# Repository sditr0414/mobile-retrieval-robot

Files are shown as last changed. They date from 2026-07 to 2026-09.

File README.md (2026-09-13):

# Mobile Retrieval Robot

STM32F411 기반 5자유도 로봇팔과 4WD 이동 플랫폼입니다. Flutter 앱으로
HC-05를 통해 차량, 로봇팔, 티칭과 상대 Yaw PID를 제어합니다.

[GitHub 저장소](https://github.com/sditr0414/mobile-retrieval-robot)

[Canva 발표 자료](https://canva.link/0yyf17uj8df1qjl)

[Notion 프로젝트 문서](https://app.notion.com/p/56bdbc6c27e2832ca4c20163aa6199b3)

## 구성

```text
Smartphone ── Bluetooth ── HC-05 ── UART ── STM32F411
                                               ├─ I2C1 ── PCA9685 ── Servo × 6
                                               ├─ I2C3 ── MPU6050
                                               └─ PWM/GPIO ── L298N ── DC Motor × 4
```

## 최종 구성

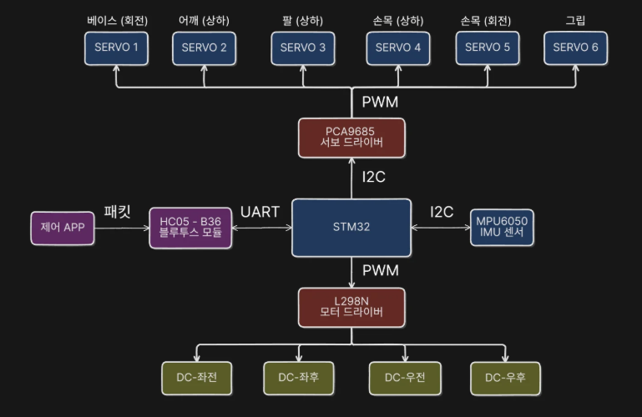
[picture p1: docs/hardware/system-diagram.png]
전체 시스템 다이어그램


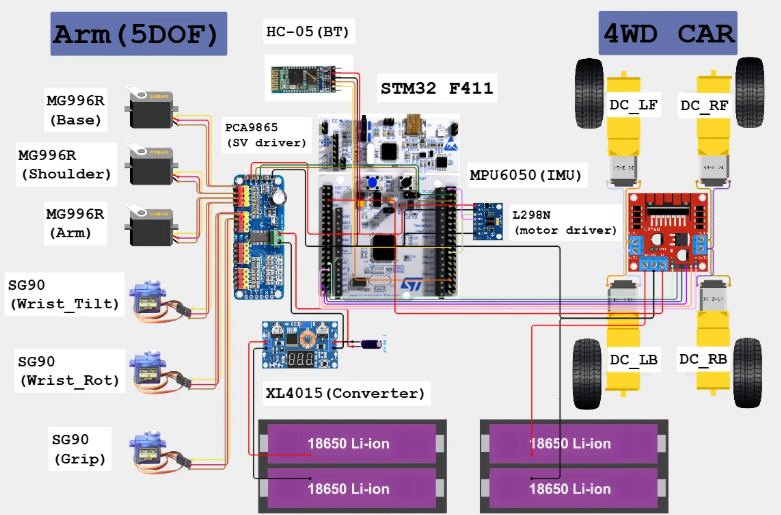
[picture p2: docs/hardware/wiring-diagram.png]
최종 하드웨어 배선도


| 폴더 | 내용 |
|---|---|
| `app/` | Flutter Android 제어 앱 |
| `firmware/` | STM32CubeMX CMake 펌웨어 |
| `simulator/` | PyBullet 로봇팔 시뮬레이터 |
| `docs/` | 하드웨어, 프로토콜, 협업 문서 |

## 구현 상태

- 고정 16바이트 Bluetooth 명령·ACK
- PCA9685 6채널 서보와 S-curve 이동
- L298N 4WD 제어, E-STOP, 500 ms 통신 타임아웃
- 앱 최대 220 PWM과 조절 가능한 PID 직진 판정 범위
- 이름을 포함한 12개 티칭 시퀀스와 PID·서보 보정값의 Sector 7 저장
- MPU6050 상대 Yaw와 직진·후진 방향 안정화 PID
- Flutter 차량·로봇팔·티칭 UI
- PyBullet 관절·패킷·PID 검증

발전 방향: 장애물 감지, 휠 엔코더 기반 정밀 주행, 절대 방향 보정,
역기구학과 XYZ 제어.

## 시작

```powershell
git clone https://github.com/sditr0414/mobile-retrieval-robot.git
cd mobile-retrieval-robot
git switch develop
```

- 앱: [app/README.md](app/README.md)
- 펌웨어: [firmware/README.md](firmware/README.md)
- 시뮬레이터: [simulator/README.md](simulator/README.md)
- 부품과 전원: [docs/hardware/bom.md](docs/hardware/bom.md)
- 핀맵: [docs/hardware/pin-map.md](docs/hardware/pin-map.md)
- PCA9685·S-curve: [docs/hardware/servo-control.md](docs/hardware/servo-control.md)
- 서보 보정: [docs/hardware/servo-calibration.md](docs/hardware/servo-calibration.md)
- IMU: [docs/hardware/imu.md](docs/hardware/imu.md)
- 상대 Yaw PID: [docs/hardware/yaw-pid.md](docs/hardware/yaw-pid.md)
- Bluetooth 규격: [docs/protocol/bluetooth-protocol.md](docs/protocol/bluetooth-protocol.md)
- 협업: [docs/collaboration/CONTRIBUTING.md](docs/collaboration/CONTRIBUTING.md)

## 안전

- 서보와 모터 전원은 STM32에서 공급하지 않습니다.
- 서보용·차량용 2S 팩의 양극은 분리하고 GND만 공통으로 연결합니다.
- 고전류 귀환은 STM32 보드를 경유하지 않습니다.
- 현재 BMS, 퓨즈와 물리 비상정지는 없습니다. 앱 E-STOP은 전원을 물리적으로
  차단하지 않습니다.
- 전원을 넣기 전에 배선, 관절 간섭과 작업 공간을 확인합니다.

<!-- contributor update -->

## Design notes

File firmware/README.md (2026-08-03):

# STM32F411 펌웨어

NUCLEO-F411RE용 STM32CubeMX CMake 프로젝트입니다. HAL과 FreeRTOS
CMSIS-RTOS2를 사용합니다.

## 구현

| 모듈 | 역할 |
|---|---|
| `bluetooth` | USART1 circular DMA와 16바이트 프레임 검증 |
| `servo_driver` | PCA9685 50 Hz PWM |
| `robot_arm` | 6채널 S-curve 이동과 시퀀스 재생 |
| `drive_4wd` | L298N, 타임아웃과 상대 Yaw PID |
| `teaching_storage` | 티칭·설정 Sector 7 저장 |
| `imu` | MPU6050 보정·필터·상대 Yaw |

```text
mobile_retrieval_robot/
├─ App/Inc, App/Src   애플리케이션 모듈
├─ Core/              CubeMX 사용자 코드
├─ Drivers/           STM32 HAL
├─ Middlewares/       FreeRTOS
├─ cmake/             CubeMX CMake
├─ CMakeLists.txt
├─ CMakePresets.json
└─ mobile_retrieval_robot.ioc
```

## CubeMX 기준

| 항목 | 설정 |
|---|---|
| HSE / SYSCLK | 8 MHz bypass / 100 MHz |
| USART1 | PA9/PA10, 9600 8-N-1 |
| RX DMA | DMA2 Stream2, Circular, 128바이트 버퍼 |
| I2C1 | PCA9685, PB8/PB9, 100 kHz |
| I2C3 | MPU6050, PA8/PC9, 100 kHz |
| TIM2 | PSC=4, ARR=999, PA0/PA1, 20 kHz |
| 모터 초기 출력 | GPIO/PWM 모두 0 |

PCA9685가 서보 PWM 50 Hz를 생성합니다. PA2/PA3와 MPU6050 INT는 사용하지
않습니다.

## 실행 구조

| 태스크 | 우선순위 | 역할 |
|---|---|---|
| Bluetooth | AboveNormal | DMA 파싱과 큐 전달 |
| Arm | Normal | 로봇팔, 티칭, 설정, Flash |
| Drive | High | 모터, 타임아웃, PID |
| IMU | BelowNormal | 3초 보정과 20 ms 측정 |
| Status | Low | PID·IMU 상태 송신 |

PCA9685는 `i2cMutex`, MPU6050은 `imuI2cMutex`, Flash는 `flashMutex`로
직렬화합니다. ISR은 파싱, 제어와 Flash 작업을 하지 않습니다.

## 제어와 안전

- 부팅 시 E-STOP 잠금, 차량 정지, 서보 출력 OFF.
- 차량 명령 500 ms 타임아웃.
- 로봇팔·티칭·Flash·IMU 보정 중 차량 인터록.
- 모터 역전 전 중립 정지.
- PCA9685 오류 시 1초마다 재초기화하며 다른 기능은 유지.
- Assert 전 차량 GPIO/PWM을 0으로 설정.

로봇팔은 20 ms 5차 S-curve와 앱 속도 `50~100%`를 사용합니다. `100%`의
각속도 상한은 약 `62.5°/s`입니다. 이동 시간은 20 ms부터 25%씩 늘리며 모든
관절의 속도·가속도·저크 제한을 만족하는 가장 짧은 후보로 결정합니다. 원점은
`[90,90,90,90,90,0]`, 이동 자세는 티칭 시퀀스 9이며 현재 Gripper를
유지합니다. 위치 피드백이 없어 첫 활성화의 실제 시작 위치와 물리 속도는
보장하지 않습니다.

서보 보정값은 Sector 7을 우선합니다. Flash가 비었을 때 일반 관절은
`700/1500/2300 µs`, Gripper는 `1200/1500/1800 µs` 안전 초기값을 사용하며
실측 끝점을 뜻하지 않습니다.

티칭 화면의 편집본은 업로드 임시 버퍼에서 재생하므로 Sector 7을 지우거나
기록하지 않습니다. 저장된 시퀀스 조회와 차량 전용 동작은 부팅 시 Flash에서
읽은 RAM 원본을 사용합니다.

MPU6050은 AD0=GND(`0x68`), 20 ms polling, 2 Hz 필터와 Z축 0.15 dps
deadband를 사용합니다. PID는 직진·후진 구간의 상대 Yaw에만 적용합니다.

## Flash

- Sector 7: `0x08060000`, 128 KiB.
- 링커 FLASH: 384 KiB.
- 현재 버전 저장 이미지는 2,516바이트이며 기록 전 Sector 7 전체를 삭제.
- 형식 버전 8, CRC와 기록 후 재검증.
- 이름을 포함한 12개 시퀀스, PID, 서보 3점 보정, 호환용 이동 자세 5바이트.
- 버전 2~7은 웨이포인트와 설정을 보존하고 기본 이름을 추가하며, 버전 1은
  Gripper 의미가 달라 거부.
- 설정 조각은 RAM에 모두 받은 뒤 COMMIT에서 한 번 기록.
- Sector 삭제·기록 중 전원을 끄면 저장 이미지가 무효화될 수 있으므로 완료 ACK 후
  전원을 차단.

정확한 패킷과 저장 ACK는
[Bluetooth 프로토콜](../docs/protocol/bluetooth-protocol.md)을 따릅니다.

## 빌드

```powershell
cd firmware/mobile_retrieval_robot
cmake --preset Debug
cmake --build --preset Debug
```

## 남은 실기 튜닝

- Wrist Tilt 포함 관절 안전 끝점
- 실제 차체 PID 계수

전원, MPU6050 장착 방향과 L298N 전진 극성은 실물에 적용되어 있습니다.
구체적인 전원 모델·출력값은 저장소 문서에 기록하지 않았습니다.

관련 문서: [핀맵](../docs/hardware/pin-map.md),
[서보 보정](../docs/hardware/servo-calibration.md),
[PCA9685·S-curve](../docs/hardware/servo-control.md),
[IMU](../docs/hardware/imu.md),
[상대 Yaw PID](../docs/hardware/yaw-pid.md).

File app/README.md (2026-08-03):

# Flutter 제어 앱

HC-05 Bluetooth Classic SPP로 STM32를 제어하는 Android 앱입니다.

## 실행

스마트폰에서 HC-05를 먼저 페어링합니다.

```powershell
cd app
flutter pub get
flutter run
```

Android Bluetooth 권한, 외부 구동 전원, 공통 GND와 로봇 작업 공간을 먼저
확인합니다.

## 화면

| 화면 | 기능 |
|---|---|
| 차량 | 조이스틱, 전용 시퀀스, PID 설정·상태 |
| 로봇팔 | 6채널 수동 제어, 속도, 원점 보정 |
| 티칭 | 웨이포인트 편집, Flash 업로드·재생·초기화 |

연결과 STOP은 모든 화면에서 접근할 수 있습니다. 세로 화면은 아래쪽, 가로
화면은 왼쪽 탐색 메뉴를 사용합니다.

## 최초 연결

1. HC-05에 연결합니다.
2. 초기 STOP 잠금을 사용자 확인 후 해제합니다.
3. 로봇팔 화면에서 `원점으로 이동`을 눌러 출력을 활성화합니다.
4. 실제 원점 도착을 눈으로 확인합니다.
5. 차량 화면 진입 시 티칭 시퀀스 9가 완료될 때까지 기다립니다.

일반 서보에는 위치 피드백이 없습니다. 앱의 값은 실측 위치가 아니라 마지막
명령입니다. 로봇팔 ACK가 10초 동안 없으면 앱은 STOP을 요청합니다.

## 차량

- 조이스틱 입력 중 약 100 ms마다 명령 전송.
- 조이스틱 최대 출력은 `220 PWM`이며 펌웨어 PID가 사용할 보정 여유를 남김.
- 손을 떼면 정지. 펌웨어는 500 ms 타임아웃 적용.
- 차량 화면 진입 시 이동 자세인 시퀀스 9 재생.
- 이동 자세 실행 중 그리퍼는 현재값 유지.

| 시퀀스 | 용도 | 조건 |
|---:|---|---|
| 9 | 이동 자세 | 차량 화면 진입·이동 요청 |
| 10 | 잡기 위치 | 독립 실행 |
| 11 | 잡기 | 시퀀스 10 완료 후 |
| 12 | 놓기 | 시퀀스 11 완료 후 |

시퀀스 9~12는 이름을 바꿀 수 없으며 잠금 아이콘과 용도별 색으로 구분합니다.
시퀀스 11 뒤 첫 주행과 시퀀스 12 완료 뒤에는 그리퍼를 유지한 이동 자세를
먼저 실행합니다. 실제 자세는 티칭 후 Flash에 업로드합니다.

PID는 차량 화면 팝업에서 저장·활성화합니다.

- Kp `0.00~2.55`, Ki/Kd `0~100`.
- 초기값 `2.00/1.40/0.00`.
- 조이스틱 직진 판정 범위는 `0.00~1.00`, 기본 `0.10`.
- PID 직진 중에는 판정 범위를 `+0.04` 넓혀 경계에서 반복 전환되는 것을 방지.
- 직진 판정 범위는 앱 실행 중 유지되며 STM32 Flash에는 저장하지 않음.
- MPU6050 보정 완료와 STOP 해제 후 활성화 가능.
- 회전에는 적용하지 않고 직진·후진 구간의 상대 Yaw만 유지.
- ACK의 실제 적용 상태만 `PID 적용 중`으로 표시.
- 목표·현재 Yaw, 오차, 출력, 좌우 PWM과 온도를 표시.
- 상태가 1.5초 이상 갱신되지 않으면 수신 대기로 표시.

## 로봇팔

| 대상 | 표시 범위 |
|---|---:|
| Base~Wrist Rotate | `-90~+90°` |
| Gripper | 열림 `0%`~닫힘 `100%` |
| 속도 | `50~100%` |

원점은 5관절 `0°`, Gripper `0%`입니다. 이동은 20 ms 5차 S-curve를 사용합니다.
속도 `100%`의 각속도 상한은 약 `62.5°/s`이며 이동 시간은 6개 관절의
속도·가속도·저크 제한을 모두 만족하도록 자동 결정됩니다.
슬라이더 트랙 탭은 값이 순간 이동하지 않으며 `-`/`+`는 짧게 누르면 한 단계,
300 ms 이상 누르면 연속 조정합니다.

### 원점 보정

1. `원점 보정`을 누르고 전체 원점 이동 ACK를 기다립니다.
2. Base부터 Gripper까지 한 관절씩 선택합니다.
3. 일반 관절은 `-90/0/+90°`, Gripper는 열림/닫힘 펄스를 조정합니다.
4. `확인 시퀀스`로 시험합니다.
5. `원점 보정 저장`으로만 Sector 7에 기록합니다.

| 대상 | 펄스 범위 |
|---|---:|
| Base~Wrist Rotate | `350~2650 µs` |
| Gripper | `1000~2000 µs` |

보정 중 다른 관절은 원점을 유지하고 차량은 잠깁니다. 자세와 실측값은
[서보 보정 문서](../docs/hardware/servo-calibration.md)를 기준으로 합니다.

## 티칭

- 12개 시퀀스, 시퀀스당 최대 30개 웨이포인트.
- 시퀀스 1~8은 UTF-8 21바이트 이하 이름을 지정해 웨이포인트와 함께 저장.
- 시퀀스 9~12는 이동 자세·잡기 위치·잡기·놓기 고정 이름 사용.
- 로봇팔 화면에서 현재 자세를 앱 목록에 추가·삭제.
- 티칭 화면에서 각도 수정, 편집본 재생과 Flash 저장·초기화.
- HC-05 연결 후 티칭 화면에 들어가면 저장된 시퀀스 이름을 불러옴.
- 업로드·초기화 중 화면 전환과 데이터 수정 잠금.
- 미저장 편집본은 시퀀스 변경 또는 앱 종료 시 폐기.
- 성공 ACK를 받은 뒤에만 저장·초기화 완료로 표시.
- 저장·초기화 완료 안내 전에는 앱을 종료하거나 로봇 전원을 끄지 않음.
- `시퀀스 재생`은 현재 편집본을 임시 전송하므로 Flash 저장 없이 바로 반영.
- 재생 완료 ACK 뒤 마지막 웨이포인트를 로봇팔 수동 제어 화면에 반영.
- 이동 자세는 마지막 웨이포인트의 5관절만 반영하고 현재 Gripper 값을 유지.
- 저장하지 않고 다른 시퀀스를 고르면 변경을 버리고 선택한 Flash 원본을 자동 조회.
- 차량 화면의 이동·잡기 위치·잡기·놓기는 편집본이 아닌 Flash 저장본 재생.
- 저장본의 마지막 자세 조회부터 재생 완료까지 중복 조작을 잠그며, 조회 실패 시
  실제 동작을 시작하지 않음.

## TEST 모드

화면 제목을 길게 눌러 Bluetooth 없는 기능 확인 모드를 켭니다. 실제 패킷이나
Flash를 변경하지 않으며 실제 Bluetooth 연결 중에는 시작할 수 없습니다.

## 프로토콜과 점검

패킷은 고정 16바이트입니다. 바이트 규격은
[Bluetooth 프로토콜](../docs/protocol/bluetooth-protocol.md)을 따릅니다.

```powershell
cd app
flutter analyze
flutter test
flutter build apk --debug
```

`flutter_classic_bluetooth 0.1.8`은 현재 빌드되지만 Kotlin Gradle 적용 경고가
있습니다. Flutter가 해당 방식을 제거하기 전에 대체 플러그인을 실기기에서
검증합니다.

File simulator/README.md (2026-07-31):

# PyBullet 시뮬레이터

앱·펌웨어와 같은 관절 순서, 방향과 Mode 1 패킷을 PC에서 확인하는 독립 검증
도구입니다.

## 설치와 실행

```powershell
cd simulator
python -m venv .venv
.\.venv\Scripts\Activate.ps1
python -m pip install -r requirements.txt
python main.py
```

```powershell
python main.py --pose travel
python main.py --emit-packets --speed 50
python main.py --direct --duration 0.2 --no-realtime-sleep
```

Windows는 `pybullet-arm64`, 다른 운영체제는 `pybullet`을 사용하도록
`requirements.txt`에 조건이 설정되어 있습니다.

## 기준

| 대상 | 값 |
|---|---|
| 관절 | Base, Shoulder, Elbow, Wrist Tilt, Wrist Rotate, Gripper |
| 앱 범위 | 5관절 `-90~+90°`, Gripper `0~100%` |
| URDF 부호 | `[-1,-1,+1,-1,-1]` |
| 원점 | `[0,0,0,0,0]`, Gripper `0%` |
| 이동 자세 | `[0,-50,90,0,60]`, Gripper `0%`로 시작 |

실제 펌웨어의 이동 자세는 티칭 시퀀스 9이며 현재 Gripper를 유지합니다.
시뮬레이터의 범위와 이동 자세는 실물 안전 범위가 아닙니다.

`protocol.py`는 다음 고정 16바이트 Mode 1 프레임을 생성합니다.

```text
[AA,01,Base,Shoulder,Elbow,WristTilt,WristRotate,Gripper,
 Control,TransactionId,Speed,00,00,00,Checksum,55]
```

## 검증

```powershell
python -m unittest discover -s tests -v
python tools\validate_model.py
python main.py --direct --duration 0.1 --pose travel --emit-packets --no-realtime-sleep
```

모델 검사는 URDF, 메시, 질량, 관성텐서, 관절 설정과 DIRECT 로딩을 확인합니다.

## 활용과 확장

- 질량은 실측값, 링크 길이는 캡처 치수를 5 mm 단위로 정리한 값입니다.
- 무게중심·관성·충돌 형상은 관절과 패킷 검증용 근사값입니다.
- 기본 중력은 0이며 `drive_pid.py`로 펌웨어 PID 계산을 재현합니다.
- 실측 동역학, 차량 모델과 역기구학을 추가해 검증 범위를 넓힐 수 있습니다.

모델 세부값은 [models/README.md](models/README.md)를 확인합니다.

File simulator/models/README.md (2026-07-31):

# 로봇팔 모델

`robot_arm.urdf`와 영문 `snake_case` STL을 보관합니다. 질량은 실측값이며
무게중심·관성텐서와 충돌 형상은 PyBullet용 근사값입니다.

## 질량

| 구분 | 합계 |
|---|---:|
| 출력 부품 16개 | 269.22 g |
| MG996R 3개 | 165.00 g |
| SG90 3개 | 27.00 g |
| URDF 전체 | 461.22 g |

볼트, 너트, 혼과 배선은 포함하지 않습니다. 부품별 값은
`mass_properties.json`, 검증 상태는 `model_parameters.json`이 기준입니다.

## 링크 길이

| 구간 | URDF |
|---|---:|
| 베이스 높이 | 60 mm |
| Base–Shoulder | 40 mm |
| Shoulder–Elbow | 120 mm |
| Elbow–Wrist | 120 mm |
| Wrist–Gripper 끝 | 125 mm |

## STL 방향

- Base: 수직축 180°
- Base cover: 높이 0 mm
- Central shaft: 높이 60 mm, X축 -90°
- Upper arm: 링크축 왼쪽 90°, 앞뒤 180°
- Wrist: Y축 180°
- Gripper: 링크축 왼쪽 90°

Base와 Base cover는 고정부품입니다. Gripper는 반대 방향으로 회전하는 두
링크로 근사합니다. 관절 제한, 토크와 충돌 안전 판단에는 사용하지 않습니다.

기준 이미지는 `left_side_view.png`, `right_side_view.png`, `top_view.png`,
`bottom_view.png`, `back_view.png`, `gripper_front_view.png`입니다.

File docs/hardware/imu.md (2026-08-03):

# MPU6050

상대 Yaw PID의 수식, 적용 조건과 튜닝은
[상대 Yaw PID 제어 문서](yaw-pid.md)를 참고합니다.

## 연결

| MPU6050 | NUCLEO-F411RE |
|---|---|
| VCC | 실물 적용, 공급전압 문서 미기록 |
| GND | 공통 GND |
| SCL / SDA | PA8 / PC9 |
| AD0 | GND, 주소 `0x68` |
| INT | 미사용 |

MPU6050은 I2C3 100 kHz와 전용 `imuI2cMutex`를 사용합니다. PCA9685의
I2C1과 분리되어 센서 버스 오류가 서보 통신에 영향을 주지 않습니다.

## 동작

1. 호환 센서 ID `0x68`, `0x70`, `0x71`, `0x73` 확인.
2. 가속도 ±2g, 자이로 ±250 dps 설정.
3. 정지 상태에서 3초 자이로 영점 보정.
4. 20 ms마다 측정하고 2 Hz 저역통과 필터 적용.
5. X/Y축 0.30 dps, Z축 0.15 dps deadband 적용.
6. Z축 각속도를 적분해 `-180~+180°` 상대 Yaw 생성.

PID를 켤 때도 차량을 먼저 정지하고 3초 영점 보정을 다시 수행합니다. 앱은 보정
완료 ACK를 받은 뒤 PID 활성화를 요청합니다.

센서 오류 시 1초마다 재연결합니다. 수동 차량·로봇팔·티칭은 유지하지만 PID를
끄고 차량을 정지한 뒤 새 주행 명령을 요구합니다.

## 방향 PID

- 직진·후진 시작 시 현재 Yaw를 목표로 저장.
- 회전에는 PID를 적용하지 않음.
- 장착 방향 보정 부호 `-1`, 후진 시 다시 반전.
- 적분항 `±50`, 최종 보정 `±80 PWM` 제한.
- 앱의 기본 주행 PWM은 최대 `220`; 펌웨어 PID 출력은 `0~255` 범위에서 보정.
- 정지, 회전, 방향 전환, E-STOP, 타임아웃과 인터록에서 상태 초기화.
- 초기 계수 `Kp=2.00`, `Ki=1.40`, `Kd=0.00`.

MPU6050에는 자력계가 없어 절대 Yaw를 보정하지 않습니다. 온도는 앱 표시용이며
보정에는 사용하지 않습니다. 장착 방향과 필터·PID 계수는 실제 차체에서 다시
확인합니다.

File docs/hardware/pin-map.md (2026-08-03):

# NUCLEO-F411RE 핀맵

현재 `.ioc`와 펌웨어 기준입니다.

## STM32 핀 배치

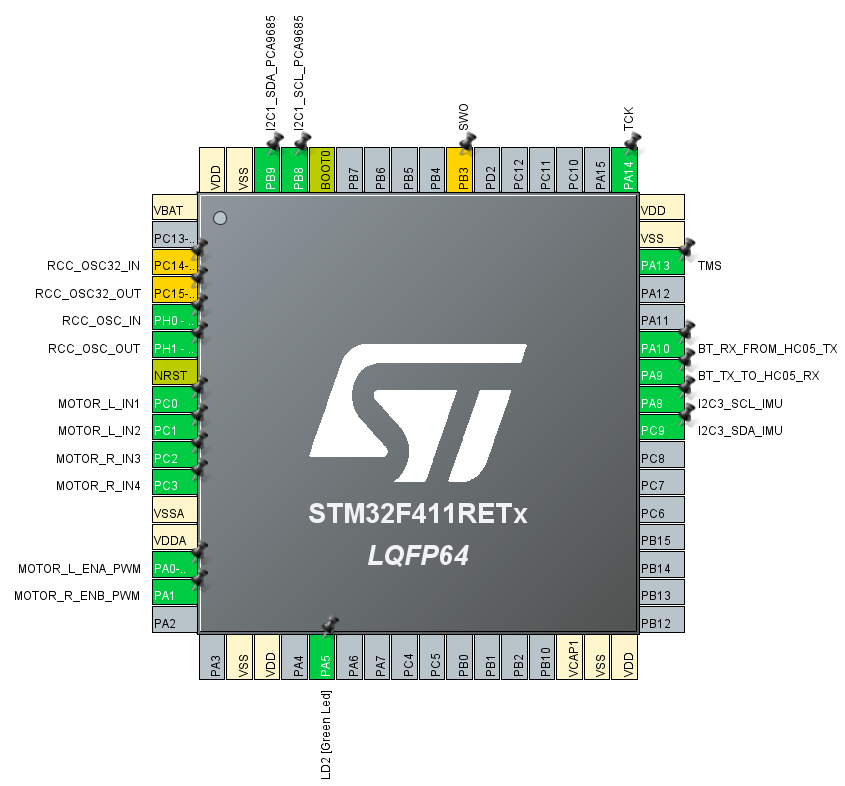
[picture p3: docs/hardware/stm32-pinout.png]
STM32F411RE CubeMX 핀 배치


## 최종 배선도

최종 하드웨어 배선도

## I2C1

| 장치 핀 | STM32 | 조건 |
|---|---|---|
| PCA9685 SCL | PB8 | `I2C1_SCL_PCA9685` |
| PCA9685 SDA | PB9 | `I2C1_SDA_PCA9685` |

PCA9685 주소는 `0x40`, 통신 속도는 100 kHz입니다.

## I2C3

| 장치 핀 | STM32 | 조건 |
|---|---|---|
| MPU6050 SCL | PA8 | `I2C3_SCL_IMU` |
| MPU6050 SDA | PC9 | `I2C3_SDA_IMU` |
| MPU6050 AD0 | GND | 주소 `0x68` |
| MPU6050 INT | 미연결 | 20 ms polling |
| MPU6050 VCC | 실물 적용 | 공급전압 문서 미기록 |

통신 속도는 100 kHz입니다. 두 모듈의 pull-up과 논리 전압은 실물에서 각각
확인합니다.

## Bluetooth

| 기능 | STM32 | HC-05 |
|---|---|---|
| USART1 TX | PA9 | RXD |
| USART1 RX | PA10 | TXD |

설정은 9600 baud, 8-N-1입니다.

## L298N

| 기능 | STM32 | 역할 |
|---|---|---|
| ENA | PA0 / TIM2_CH1 | 왼쪽 20 kHz PWM |
| IN1 | PC0 | 왼쪽 방향 |
| IN2 | PC1 | 왼쪽 방향 |
| ENB | PA1 / TIM2_CH2 | 오른쪽 20 kHz PWM |
| IN3 | PC2 | 오른쪽 방향 |
| IN4 | PC3 | 오른쪽 방향 |

ENA/ENB 점퍼를 제거합니다. 좌우 전진 극성은 실제 L298N·모터 배선에 맞춰 적용했습니다.

## 기타

| 기능 | 핀 |
|---|---|
| SWD | PA13, PA14 |
| 예비 | PA2, PA3 |

## 전원·GND

- PCA9685 `VCC`: STM32 논리 전원.
- PCA9685 `V+`: XL4015 서보 전원.
- PCA9685 `V+`–GND: 1000 µF 전해 커패시터.
- 차량용 2S: L298N 모터 전원.
- STM32, PCA9685, L298N, HC-05, MPU6050과 두 전원은 공통 GND.
- 서보·모터 고전류 귀환은 STM32 보드를 경유하지 않음.
- STM32 VIN용 DC-DC는 실물 적용 완료. 모델·출력값은 문서 미기록.

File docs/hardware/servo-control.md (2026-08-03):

# PCA9685와 S-curve 서보 제어

이 문서는 로봇팔의 목표 자세가 PCA9685 PWM 출력으로 변환되는 과정과
서보를 부드럽게 움직이는 5차 S-curve를 설명합니다. 발표 자료의 제어 흐름을
참고하되, 수치와 채널은 현재 펌웨어를 기준으로 합니다.

전체 시스템 다이어그램

## 전체 흐름

```text
앱의 목표 자세와 속도
  → 16바이트 Bluetooth 패킷
  → 5차 S-curve 궤적 계산
  → 20 ms마다 다음 관절 위치 계산
  → 관절별 3점 보정으로 펄스폭 변환
  → 펄스폭을 PCA9685 12비트 Count로 변환
  → I2C1 레지스터 기록
  → 서보 PWM 출력
```

## PCA9685 역할

STM32의 타이머 채널을 서보마다 사용하지 않고 PCA9685 한 개가 6개 서보의
PWM을 생성합니다. 모든 채널은 같은 50 Hz 주기를 사용하지만 펄스폭은 채널마다
독립적으로 설정합니다.

| 항목 | 현재 설정 |
|---|---|
| 연결 | I2C1 PB8/PB9, 100 kHz |
| 주소 | `0x40` |
| PWM 주파수 | 50 Hz |
| PWM 주기 | 20,000 µs |
| 분해능 | 12비트, 4,096 Count |
| Prescale | 121 |
| 사용 채널 | 0~5 |

| 채널 | 관절 |
|---:|---|
| 0 | Base |
| 1 | Shoulder |
| 2 | Elbow |
| 3 | Wrist Tilt |
| 4 | Wrist Rotate |
| 5 | Gripper |

Canva의 `1056 µs → 216 Count`는 변환 과정을 보여주는 예시입니다. 실제 Shoulder
출력은 현재 채널 1을 사용하며, 펄스폭은 저장된 관절 보정값에 따라 달라집니다.

### I2C 통신 방식

STM32가 Master, PCA9685가 Slave입니다. SCL은 STM32가 만드는 클록이고 SDA는
주소·레지스터·데이터를 주고받는 선입니다. 두 선은 Open-drain 방식이므로 pull-up이
필요합니다. 실제 모듈의 pull-up 저항값은 문서에 기록되지 않아 임의로 지정하지
않습니다.

PCA9685의 7비트 주소는 `0x40`입니다. I2C 버스에서는 이 주소 뒤에 Read/Write
비트가 붙습니다.

```text
7비트 장치 주소 : 0x40 = 100 0000₂
Write 주소 바이트: 0x80 = 1000 0000₂
Read 주소 바이트 : 0x81 = 1000 0001₂
```

STM32 HAL은 주소 인수에 Read/Write 비트가 들어갈 자리를 포함하므로 코드에서는
`0x40 << 1`, 즉 `0x80`을 `HAL_I2C_Mem_Write()`에 전달합니다. HAL이 실제 전송
방향에 맞춰 최하위 비트를 처리합니다.

한 채널을 기록하는 순서는 다음과 같습니다.

```text
START
  → PCA9685 주소 + Write
  → ACK
  → 시작 레지스터 주소
  → ACK
  → ON_L → ACK → ON_H → ACK → OFF_L → ACK → OFF_H → ACK
  → STOP
```

`MODE1`의 Auto Increment를 켰기 때문에 시작 레지스터 하나를 지정한 뒤 네 바이트를
연속 전송할 수 있습니다. 펌웨어의 `HAL_I2C_Mem_Write()`가 START, 주소, ACK 확인,
레지스터 주소와 데이터 전송, STOP을 처리합니다. ACK가 없거나 100 ms 안에 전송이
끝나지 않으면 오류를 반환합니다.

### 채널 레지스터

채널마다 ON 시점과 OFF 시점을 저장하는 네 레지스터가 있습니다.

| 순서 | 레지스터 | 내용 |
|---:|---|---|
| 0 | `LEDn_ON_L` | ON Count 하위 8비트 |
| 1 | `LEDn_ON_H` | ON Count 상위 4비트, Full ON 비트 |
| 2 | `LEDn_OFF_L` | OFF Count 하위 8비트 |
| 3 | `LEDn_OFF_H` | OFF Count 상위 4비트, Full OFF 비트 |

채널 0의 시작 주소는 `0x06`이고, 다음 채널은 네 바이트 뒤에 있습니다.

```text
채널 n 시작 주소 = 0x06 + 4 × n

채널 0 Base          : 0x06
채널 1 Shoulder      : 0x0A
채널 2 Elbow         : 0x0E
채널 3 Wrist Tilt    : 0x12
채널 4 Wrist Rotate  : 0x16
채널 5 Gripper       : 0x1A
```

### 12비트 카운터

12비트는 `2¹² = 4096`단계를 표현합니다. 내부 카운터는 한 PWM 주기 동안
`0~4095`를 반복합니다. Count가 ON 값에 도달하면 출력이 활성화되고 OFF 값에
도달하면 비활성화됩니다.

```text
Count: 0 ───────────────────────────────────────────── 4095
       ↑ ON=0                 ↑ OFF=N
       └────── HIGH 구간 ─────┘
```

현재 펌웨어는 모든 채널의 ON Count를 0으로 두고 OFF Count만 바꿉니다. 따라서
OFF Count가 곧 펄스폭을 나타냅니다. ON과 OFF 값을 모두 다르게 주면 펄스의 시작
위치도 옮길 수 있지만, 일반 서보 제어에는 필요하지 않아 사용하지 않습니다.

### 펄스폭을 Count로 변환

20,000 µs를 4,096등분하므로 한 Count는 약 4.883 µs입니다.

```text
OFF Count = round(펄스폭 µs × 4096 / 20000)
```

예를 들어 1,500 µs는 307 Count이고 `0x0133`입니다. Shoulder 채널 1에 이를
출력하면 시작 주소 `0x0A`부터 다음 네 바이트를 기록합니다.

```text
LED1_ON_L  = 0x00
LED1_ON_H  = 0x00
LED1_OFF_L = 0x33
LED1_OFF_H = 0x01
```

Canva의 1,056 µs 예시는 같은 식으로 약 216 Count가 됩니다.

```text
round(1056 × 4096 / 20000) = 216
```

상위 레지스터에는 Count의 상위 4비트만 저장합니다. 비트 4는 일반 Count가 아니라
Full ON 또는 Full OFF 제어 비트입니다. 전체 출력 차단 시에는
`ALL_LED_OFF_H`의 Full OFF 비트를 사용합니다.

### 50 Hz와 Prescale

PCA9685의 모든 채널은 하나의 PWM 주파수를 공유합니다. 내부 발진기의 대표값
25 MHz를 사용할 때 주파수와 Prescale 관계는 다음과 같습니다.

```text
PWM 주파수 = 발진 주파수 / (4096 × (Prescale + 1))
Prescale = round(발진 주파수 / (4096 × 목표 주파수)) - 1

50 Hz 설정 = round(25,000,000 / (4096 × 50)) - 1 ≈ 121
```

대표 발진값으로 계산하면 `Prescale=121`에서 약 50.03 Hz입니다. 실제 내부 발진기는
오차가 있으므로 정확한 펄스폭이 필요하면 출력 주기를 측정하고 서보 3점 보정값에
반영합니다.

### 각도를 펄스폭으로 변환

서보마다 중앙과 양 끝의 실제 펄스폭이 다르므로 하나의 고정 비율을 사용하지
않습니다. `-90°`, `0°`, `+90°`에서 저장한 세 점을 두 구간으로 나눠 선형
보간합니다.

```text
-90° ~ 0°  : 최소 펄스 ↔ 중앙 펄스
  0° ~ 90° : 중앙 펄스 ↔ 최대 펄스
```

앱의 일반 관절 `-90~+90°`는 패킷 내부의 `0~180`으로 전달됩니다. Gripper는
앱의 열림 `0%`부터 닫힘 `100%`를 내부 `0~180`으로 변환합니다. 조립 방향이
반대인 관절은 펄스 변환 전에 논리 위치를 반전합니다.

보정 가능한 범위는 일반 관절 `350~2650 µs`, Gripper `1000~2000 µs`입니다.
실측값은 [서보 보정 문서](servo-calibration.md)를 기준으로 합니다.

### 초기화와 출력 차단

1. I2C 장치 응답 확인.
2. `MODE1`을 읽고 Auto Increment와 Sleep 설정.
3. `PRE_SCALE=121` 기록.
4. Sleep 해제 후 1 ms 대기.
5. Restart와 Totem-pole 출력 설정.
6. 부팅 직후 모든 채널을 Full OFF로 유지.

PCA9685 통신은 전용 `i2cMutex`로 보호합니다. I2C 기록에 실패하면 로봇팔
출력을 차단하고 상위 태스크가 1초 간격으로 재초기화를 시도합니다.

## 5차 S-curve

목표 각도를 즉시 PWM에 적용하면 속도와 가속도가 갑자기 변해 충격, 기구 흔들림,
전류 피크가 커질 수 있습니다. 현재 펌웨어는 위치를 5차 다항식으로 만들고 20 ms
간격으로 조금씩 출력합니다.

```text
p(t) = a0 + a1t + a2t² + a3t³ + a4t⁴ + a5t⁵
```

계수는 다음 경계 조건을 만족하도록 계산합니다.

- 시작: 현재 위치, 현재 속도, 현재 가속도.
- 종료: 목표 위치, 속도 0, 가속도 0.

정지 상태에서 출발하는 기본 형태는 정규화 시간 `u=t/T`에 대해 다음과 같습니다.

```text
s(u) = 10u³ - 15u⁴ + 6u⁵,  0 ≤ u ≤ 1
p(t) = 시작 위치 + (목표 위치 - 시작 위치) × s(u)
```

`T`는 전체 이동 시간입니다. `u`는 현재 경과 시간 `t`를 `T`로 나눈 값입니다.
따라서 시작과 끝에서는 변화량이 작고 중간에서는 커져, 느리게 출발하고 가속한 뒤
목표 근처에서 다시 감속합니다.

### 속도와 이동 시간

앱 속도는 `50~100%`입니다. 최대 각속도는 다음 식을 사용합니다.

```text
최대 각속도 = 1000 / 16 × 속도 비율
             = 62.5 × 속도 비율 (°/s)
```

| 앱 속도 | 최대 각속도 |
|---:|---:|
| 50% | 약 31.25°/s |
| 80% | 약 50.0°/s |
| 100% | 약 62.5°/s |

가속 기준 시간은 `12 × 20 ms = 240 ms`입니다. 펌웨어는 이 값으로 최대
가속도와 저크를 계산합니다.

```text
최대 가속도 = 최대 각속도 / 0.24
최대 저크   = 최대 가속도 / 0.24
```

이동 시간은 고정값이 아닙니다. 20 ms부터 시작해 후보 시간을 25%씩 늘리며,
6개 관절이 모두 위치 범위와 속도·가속도·저크 제한을 지키는 가장 짧은 시간을
선택합니다. 후보 하나는 32개 구간으로 검사하며 모든 관절이 같은 시점에 끝납니다.

### 이동 중 목표 변경

새 목표가 들어오면 현재 위치뿐 아니라 현재 속도와 가속도도 시작 조건으로 사용해
새 5차 궤적을 만듭니다. 연속 궤적이 관절 범위를 벗어나면 현재 위치에서 속도와
가속도를 0으로 만든 뒤 다시 계획합니다. 지연된 20 ms 호출을 한꺼번에 실행하지
않아 I2C 출력이 순간적으로 몰리는 것도 막습니다.

## 제어의 한계

- 일반 서보에는 위치 피드백이 없어 현재 위치는 마지막 명령값입니다.
- S-curve는 명령 변화를 부드럽게 하지만 전원 부족, 전압 강하, 기구 걸림을
  해결하지는 않습니다.
- 끝점은 서보와 조립 상태마다 다르므로 앱에서 실측 보정해야 합니다.
- PCA9685의 실제 발진 오차가 크면 오실로스코프로 주기와 펄스폭을 확인한 뒤
  보정값을 다시 측정합니다.

## 구현 위치

- PCA9685 초기화·출력: `firmware/mobile_retrieval_robot/App/Src/servo_driver.c`
- S-curve·관절 제어: `firmware/mobile_retrieval_robot/App/Src/robot_arm.c`
- 실측 펄스: `docs/hardware/servo-calibration.md`
- 핀과 전원: `docs/hardware/pin-map.md`
- 발표 자료: [Canva 프레젠테이션](https://canva.link/0yyf17uj8df1qjl)
- 칩 규격: [NXP PCA9685 데이터시트](https://www.nxp.com/docs/en/data-sheet/PCA9685.pdf)

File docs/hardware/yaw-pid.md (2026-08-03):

# MPU6050 상대 Yaw PID 제어

이 문서는 MPU6050으로 계산한 상대 Yaw를 이용해 4WD 차량의 직진·후진 방향을
보정하는 과정을 설명합니다. 수식과 제한값은 현재 펌웨어를 기준으로 합니다.

전체 시스템 다이어그램

## 제어 목적

좌우 모터에 같은 PWM을 주어도 모터 편차, 바닥 마찰, 하중과 무게중심 때문에
차량은 한쪽으로 치우칠 수 있습니다. PID는 주행 시작 방향을 목표 Yaw로 저장하고,
현재 Yaw와의 차이로 좌우 PWM을 반대로 보정합니다.

```text
조이스틱 직진·후진 입력
  → 현재 Yaw를 목표로 저장
  → MPU6050 Z축 각속도 측정
  → 상대 Yaw 적분
  → 목표와 현재 Yaw의 오차 계산
  → PID 출력 계산
  → 좌우 PWM에 반대 부호로 적용
```

이 제어는 목표 지점이나 절대 방위를 찾아가는 PID가 아닙니다. MPU6050에는
자력계가 없으므로 한 번의 직진·후진 구간에서 시작 방향을 유지하는 용도입니다.

## 센서 값 생성

1. `WHO_AM_I`로 MPU6050 계열 센서 확인.
2. 가속도 ±2g, 자이로 ±250 dps 설정.
3. 차량을 정지한 상태에서 3초간 자이로 Bias 계산.
4. 20 ms마다 센서 측정.
5. Bias 제거 후 dps로 변환.
6. 2 Hz 1차 저역통과 필터 적용.
7. Z축 `±0.15 dps` deadband 적용.
8. Z축 각속도를 시간 적분해 상대 Yaw 계산.
9. Yaw를 `-180~+180°`로 정규화.

```text
Yaw(k) = Yaw(k-1) + GyroZ(k) × Δt
```

센서의 상세 연결과 필터는 [MPU6050 문서](imu.md)를 참고합니다.

## 앱에서 PID를 켜는 과정

```text
PID 설정 조회
  → 차량 정지
  → 3초 IMU 영점 보정 요청
  → 보정 완료 ACK 확인
  → PID 활성화 요청
  → 활성화 ACK 확인
  → 새 주행 명령 허용
```

- 초기 계수: `Kp=2.00`, `Ki=1.40`, `Kd=0.00`.
- 앱 설정 범위: Kp `0.00~2.55`, Ki/Kd `0~100`.
- Kp는 `0.01`, 저장값은 모든 계수를 1,000배한 정수 단위로 전송합니다.
- 계수는 Sector 7에 저장하지만 PID 활성 상태는 저장하지 않습니다.
- PID는 부팅 후 자동으로 켜지지 않습니다.
- 실행 중 계수를 바꾸지 않고 PID를 끈 뒤 저장합니다.

IMU 사용 불가, 보정 중, Flash 작업 중, 로봇팔 이동 중 또는 E-STOP 상태에서는
PID 활성화를 거부합니다. 상태 전환 중에는 모터를 먼저 정지하고 이전 주행 명령을
버리며, 전환 뒤 들어온 새 주행 명령만 사용합니다.

## 직진 판정

앱은 조이스틱 X축이 중앙 범위에 있고 전진·후진 입력이 있을 때만 좌우 PWM을
같게 만들고 `PidStraight=1`을 전송합니다.

- 기본 중앙 범위: `|X| ≤ 0.10`.
- 앱 설정 범위: `0.00~1.00`.
- PID 직진 상태 유지 범위: 설정값 `+0.04`.
- 전진·후진 입력 최소 조건: `|Y| > 0.05`.

`+0.04` 히스테리시스는 경계 부근의 작은 손 떨림 때문에 PID가 반복해서
켜졌다 꺼지는 현상을 줄입니다. 이 범위는 앱 실행 중에만 유지되며 STM32 Flash에
저장하지 않습니다.

펌웨어에서 PID가 실제 계산되려면 다음 조건을 모두 만족해야 합니다.

- PID 활성화 완료.
- IMU 사용 가능.
- `PidStraight=1`.
- 좌우 방향이 동일.
- 좌우 PWM 중 하나 이상이 0보다 큼.
- 유효한 새 주행 명령이 500 ms 안에 수신됨.
- 차량 인터록이 해제됨.

## 목표 Yaw

직진 PID가 새로 시작되거나 전진·후진 방향이 바뀌면 다음 IMU 샘플의 Yaw를
목표값으로 저장합니다. 앱이 `RefreshYaw=1`을 보낸 경우에도 목표를 갱신합니다.

```text
목표 Yaw = 직진·후진 구간 시작 시점의 현재 Yaw
```

목표를 갱신할 때 적분항, 이전 오차와 이전 샘플 시간을 초기화합니다. 회전 후 다시
직진하면 회전 전 방향이 아니라 새 방향이 목표가 됩니다.

## PID 계산

### 방향 오차

```text
오차 e(k) = 목표 Yaw - 현재 Yaw
```

오차는 가장 짧은 회전 방향이 되도록 `-180~+180°`로 변환합니다. 예를 들어
목표가 `179°`, 현재가 `-179°`이면 단순 차이 `358°`가 아니라 `-2°`를 사용합니다.

### 샘플 시간

```text
Δt = (현재 샘플 시각 - 이전 샘플 시각) / 1000
```

정상 주기는 약 20 ms입니다. 첫 샘플, 같은 시각 또는 200 ms를 넘긴 비정상 간격은
`Δt=0.02 s`, 미분항 0으로 처리해 큰 순간 미분값을 막습니다.

### P, I, D 항

```text
P = Kp × e(k)
I상태 = I상태 + Ki × e(k) × Δt
D = Kd × (e(k) - e(k-1)) / Δt

PID 출력 = P + I상태 + D
```

| 항 | 역할 | 현재 운용 의미 |
|---|---|---|
| P | 현재 오차에 즉시 반응 | 한쪽으로 틀어진 만큼 바로 좌우 PWM 차이 생성 |
| I | 누적되는 작은 오차 보정 | 지속적인 모터 편차와 하중 차이 보정 |
| D | 오차 변화 속도 억제 | 진동 완화용, 초기값은 0 |

적분 상태는 `±50`, 최종 PID 출력은 `±80 PWM`으로 제한합니다. 적분 제한은
모터 출력이 포화된 동안 값이 계속 쌓이는 wind-up을 줄입니다.

## 좌우 PWM 적용

현재 장착 방향은 보정 부호 `-1`을 사용하며 후진에서는 부호를 다시 뒤집습니다.

```text
보정값 = -PID 출력
후진이면 보정값 = -보정값

왼쪽 PWM  = 기본 왼쪽 PWM  + 보정값
오른쪽 PWM = 기본 오른쪽 PWM - 보정값
```

최종 값은 `0~255`로 제한합니다. 앱의 조이스틱 출력은 최대 `220 PWM`으로 제한해
PID가 한쪽 PWM을 올릴 여유를 둡니다. 다만 최대 증가 여유는 35이므로 큰 보정은
한쪽이 255에서 포화될 수 있습니다. 반대쪽 PWM을 낮추는 보정은 계속 적용됩니다.

Canva의 예시처럼 기본 PWM이 198이고 계산된 좌우 보정 크기가 17.89라면 한쪽은
약 180, 반대쪽은 약 216이 됩니다. 실제 어느 쪽을 높이는지는 Yaw 오차, 장착 부호와
전진·후진 방향에 따라 결정됩니다.

## 초기화되는 조건

다음 상황에서는 목표 Yaw와 PID 누적 상태를 버립니다.

- 차량 정지 또는 Engine OFF.
- 조이스틱 회전 입력.
- 전진·후진 방향 변경.
- E-STOP 설정·해제.
- 500 ms 통신 타임아웃.
- 로봇팔 이동, 티칭, Flash 작업 또는 IMU 보정 인터록.
- IMU 오류와 재연결.
- PID 활성화·비활성화 전환.

인터록 해제 전에 받은 주행 명령은 다시 사용하지 않습니다. 새 패킷이 들어와야
모터와 PID가 재개됩니다.

## 앱 상태 표시

펌웨어는 약 500 ms마다 PID 상태를 16바이트 패킷으로 보냅니다.

- 명령 수신 여부.
- PID 설정 활성 여부와 실제 연산 중 여부.
- 전진·후진 상태.
- 목표 Yaw, 현재 Yaw와 오차.
- PID 출력.
- 최종 좌우 PWM.
- IMU 사용 가능 상태.

앱은 1.5초 이상 상태가 오지 않으면 이전 값을 현재 상태처럼 표시하지 않고
수신 대기로 전환합니다. 정확한 바이트 배열은
[Bluetooth 프로토콜](../protocol/bluetooth-protocol.md)을 기준으로 합니다.

## 튜닝 순서

1. 차량을 들어 올리거나 넓고 안전한 시험 공간을 확보합니다.
2. IMU 장착 방향과 3초 보정 성공을 확인합니다.
3. `Ki=0`, `Kd=0`에서 Kp를 작은 값부터 올립니다.
4. 방향 복귀가 충분하지만 진동하지 않는 Kp를 찾습니다.
5. 한쪽으로 계속 남는 작은 오차가 있을 때 Ki를 조금씩 올립니다.
6. 빠른 진동이나 과도 응답이 있을 때만 Kd를 소량 적용합니다.
7. 저속·중속·최대 220 PWM과 전진·후진을 각각 시험합니다.
8. 안정된 계수만 Flash에 저장합니다.

Yaw 자체가 자이로 적분값이라 노이즈가 포함됩니다. Kd를 크게 하면 미세한 오차
변화가 증폭될 수 있으므로 초기값은 0입니다.

## 문제 확인

| 증상 | 우선 확인 |
|---|---|
| PID 활성화 거부 | STOP, IMU 보정, 센서 상태, 로봇팔·Flash 인터록 |
| 한쪽으로 더 심하게 틀어짐 | IMU 장착 부호, 모터 전진 극성, 후진 부호 |
| 좌우가 빠르게 흔들림 | Kp·Kd 과다, IMU 진동, 조이스틱 직진 범위 |
| 시간이 지나며 보정이 커짐 | Ki 과다, 바닥 미끄러짐, Yaw drift |
| 최대속도에서 효과 감소 | 255 PWM 포화, 앱 220 제한 적용 여부 |
| 갑자기 PID가 멈춤 | 500 ms 명령 타임아웃, IMU 오류, 인터록 상태 |

## 구현 위치

- PID 계산·모터 적용: `firmware/mobile_retrieval_robot/App/Src/drive_4wd.c`
- MPU6050 처리: `firmware/mobile_retrieval_robot/App/Src/imu.c`
- 앱 직진 판정·설정: `app/lib/main.dart`
- 패킷·ACK: `docs/protocol/bluetooth-protocol.md`
- 발표 자료: [Canva 프레젠테이션](https://canva.link/0yyf17uj8df1qjl)

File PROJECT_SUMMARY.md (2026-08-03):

# 모바일 물품 회수 로봇 프로젝트 종합 정리

> STM32F411 기반 4WD 이동 플랫폼과 5자유도 로봇팔을 Flutter 앱으로 제어하는
> 모바일 물품 회수 로봇입니다. 이 문서는 발표와 최종 검수를 위한 단일 요약본이며,
> 세부 구현의 최종 기준은 소스 코드와 `docs/` 원본 문서입니다.

[Canva 발표 자료](https://canva.link/0yyf17uj8df1qjl)

[Notion 프로젝트 문서](https://app.notion.com/p/56bdbc6c27e2832ca4c20163aa6199b3)

## 1. 프로젝트 한눈에 보기

| 항목 | 내용 |
|---|---|
| 프로젝트 목표 | 스마트폰으로 이동·물체 접근·잡기·운반·놓기 수행 |
| 메인 제어기 | NUCLEO-F411RE / STM32F411RETx |
| 이동부 | L298N과 DC 기어모터 4개를 이용한 좌우 차동 구동 |
| 로봇팔 | 회전 5축과 Gripper, 서보 총 6개 |
| 서보 제어 | PCA9685, 50 Hz PWM, 6채널 사용 |
| 무선 통신 | HC-05 Bluetooth Classic SPP, UART 9600 baud |
| 자세 센서 | MPU6050 가속도·자이로 |
| 제어 앱 | Flutter Android 앱 |
| 펌웨어 | STM32 HAL, FreeRTOS CMSIS-RTOS2, C11 |
| 빌드 | STM32CubeMX 네이티브 CMake, GCC Arm Embedded |
| 데이터 저장 | STM32 내부 Flash Sector 7 |
| 시뮬레이터 | Python과 PyBullet, 보조 검증용 |

### 핵심 구현 기능

- Flutter 앱에서 차량, 로봇팔, 티칭을 한 번에 제어.
- 고정 16바이트 Bluetooth 바이너리 패킷과 ACK.
- PCA9685 기반 6채널 서보 제어와 20 ms S-curve 이동.
- L298N 기반 4WD 차동 조향과 500 ms 통신 타임아웃.
- MPU6050 상대 Yaw 기반 직진·후진 방향 안정화 PID.
- 이름을 포함한 12개 티칭 시퀀스, 시퀀스당 최대 30개 웨이포인트.
- PID 계수와 서보 3점 보정값의 Flash 저장.
- E-STOP, 차량·로봇팔 인터록, Flash 작업 보호.

### 프로젝트 범위 밖 기능

- 초음파 거리 센서.
- 휠 엔코더와 휠 속도 폐루프 제어.
- 자력계 기반 절대 Yaw 보정.
- 역기구학과 XYZ 좌표 제어.
- 완성된 차량 동역학 시뮬레이션.
- 앱 스토어 배포와 상용 제품 수준 전원 보호 회로.

## 2. 개발 배경과 목표

일반적인 RC카는 이동만 가능하고, 고정형 로봇팔은 작업 영역이 제한됩니다.
이 프로젝트는 두 장치를 결합해 사용자가 스마트폰으로 목표물에 접근하고,
로봇팔로 물체를 잡은 뒤 다른 위치로 운반하는 과정을 구현합니다.

설계 목표는 다음과 같습니다.

1. 한 앱에서 차량과 로봇팔을 쉽게 조작.
2. 사용자가 직접 자세를 기록하는 티칭 기능 제공.
3. 실물마다 다른 서보 끝점을 앱에서 보정.
4. 통신 오류나 동작 충돌 시 차량과 로봇팔을 안전하게 정지.
5. 센서가 없어도 기본 제어가 가능하고, 센서가 있으면 직진 안정성 향상.

## 3. 전체 시스템 구성

```mermaid
flowchart LR
    APP[Flutter 제어 앱] <-->|Bluetooth Classic SPP| HC05[HC-05 B36]
    HC05 <-->|USART1 9600 baud| MCU[NUCLEO-F411RE]
    MCU <-->|I2C1| PCA[PCA9685]
    PCA --> S[서보 6개]
    MCU <-->|I2C3| IMU[MPU6050]
    MCU -->|TIM2 PWM + GPIO| L298[L298N]
    L298 --> ML[왼쪽 DC 모터 2개]
    L298 --> MR[오른쪽 DC 모터 2개]
    MCU -->|내부 Flash| F[Sector 7 티칭·설정]
```

### 최종 다이어그램

전체 시스템 다이어그램

### 최종 배선도

최종 하드웨어 배선도

### 제어 흐름

```text
사용자 입력
  → Flutter UI
  → 16바이트 명령 패킷
  → HC-05
  → USART1 circular DMA
  → BluetoothTask 검증
  → ArmQueue 또는 DriveQueue
  → 로봇팔·차량·Flash 처리
  → 16바이트 ACK/상태 패킷
  → 앱 상태 갱신
```

앱은 모든 명령의 기준입니다. 펌웨어는 잘못된 Header, Tail, Mode, Checksum,
범위 또는 예약 바이트를 가진 패킷을 폐기합니다. 무효 프레임 뒤에는 다음
`0xAA` Header를 찾아 스트림을 다시 동기화합니다.

## 4. 하드웨어 구성

### 부품 목록

| 구분 | 부품 | 수량 | 역할 |
|---|---|---:|---|
| 메인 제어 | NUCLEO-F411RE | 1 | 통신, 제어, 저장, RTOS 실행 |
| Bluetooth | HC-05 B36 | 1 | Android와 Classic SPP 통신 |
| IMU | MPU6050 모듈 | 1 | 가속도·자이로와 상대 Yaw |
| 서보 드라이버 | PCA9685 | 1 | 50 Hz 서보 PWM 생성 |
| 고토크 서보 | MG996R | 3 | Base, Shoulder, Elbow |
| 소형 서보 | SG90 | 3 | Wrist Tilt, Wrist Rotate, Gripper |
| 모터 드라이버 | L298N | 1 | 좌우 DC 모터 그룹 구동 |
| 이동부 | DC 기어모터·바퀴 | 각 4 | 4WD 이동 |
| 배터리 | 18650 | 4 | 독립된 2S 팩 2개 |
| 배터리 홀더 | 2S | 2 | 서보용·차량용 전원 분리 |
| 강압 모듈 | XL4015 | 1 | 서보 전압 강하 |
| 안정화 | 1000 µF 전해 커패시터 | 1 | PCA9685 V+ 전압 변동 완화 |
| 기구부 | 3D 출력물·체결 부품 | 1세트 | 로봇팔 링크와 고정부 |

### 로봇팔 자유도와 채널

로봇팔은 다섯 개의 자세 축과 Gripper로 구성됩니다. 따라서 기구 자유도는
5DOF이며, 실제 제어 서보는 6개입니다.

| PCA9685 채널 | 관절 | 기능 | 서보 |
|---:|---|---|---|
| 0 | Base | 좌우 회전 | MG996R |
| 1 | Shoulder | 어깨 상하 | MG996R |
| 2 | Elbow | 팔꿈치 상하 | MG996R |
| 3 | Wrist Tilt | 손목 상하 | SG90 |
| 4 | Wrist Rotate | 손목 회전 | SG90 |
| 5 | Gripper | 열기·닫기 | SG90 |

### 전원 구조

```mermaid
flowchart TD
    BS[서보용 2S 팩] --> XL[XL4015]
    XL --> VP[PCA9685 V+]
    VP --> SV[서보 6개]
    BC[차량용 2S 팩] --> L[L298N 모터 전원]
    L --> DC[DC 모터 4개]
    STM[STM32 논리 전원] --> VCC[PCA9685 VCC]
    GND[공통 GND] --- STM
    GND --- XL
    GND --- L
    GND --- VP
    GND --- HC[HC-05]
    GND --- MPU[MPU6050]
```

- PCA9685 `VCC`는 STM32 논리 전원, `V+`는 XL4015 외부 서보 전원입니다.
- 두 배터리 팩의 양극은 서로 연결하지 않습니다.
- STM32, PCA9685, L298N, HC-05, MPU6050과 두 전원의 GND는 공통입니다.
- 서보와 모터 고전류 귀환은 STM32 보드나 신호용 점퍼선을 지나지 않습니다.
- PCA9685 `V+`–GND에 1000 µF 커패시터를 연결합니다.
- L298N ENA/ENB 점퍼는 제거하고 STM32의 20 kHz PWM을 입력합니다.
- STM32 VIN용 DC-DC는 실물에 적용되어 있습니다.

### 현재 전원 구성의 한계

- BMS 미적용.
- 퓨즈 미적용.
- 구동 전원을 직접 끊는 물리 비상정지 미적용.
- 앱 E-STOP은 논리적 출력 차단이며 물리 전원 차단이 아님.

XL4015 출력과 STM32 VIN용 DC-DC는 실물에 배선·적용되어 있습니다. 구체적인
출력 전압 측정값은 저장소 문서에 기록되지 않아 이 문서에서 임의로 지정하지
않습니다.

## 5. STM32 핀 배치

STM32F411RE CubeMX 핀 배치

### I2C1

| 기능 | STM32 핀 | 연결 |
|---|---|---|
| I2C1 SCL | PB8 | PCA9685 SCL |
| I2C1 SDA | PB9 | PCA9685 SDA |

### I2C3

| 기능 | STM32 핀 | 연결 |
|---|---|---|
| I2C3 SCL | PA8 | MPU6050 SCL |
| I2C3 SDA | PC9 | MPU6050 SDA |
| MPU6050 AD0 | GND | 주소 `0x68` 선택 |
| MPU6050 INT | 미연결 | 20 ms polling 사용 |

- PCA9685 기본 주소: `0x40`.
- MPU6050 VCC와 I2C 배선은 실제 모듈 기준으로 적용되어 있습니다.
- 구체적인 MPU6050 공급전압과 모듈 pull-up 값은 저장소 문서에 미기록 상태입니다.

### Bluetooth USART1

| 기능 | STM32 | HC-05 |
|---|---|---|
| USART1 TX | PA9 | RXD |
| USART1 RX | PA10 | TXD |

- 속도: 9600 baud.
- 프레임: 8 data bits, No parity, 1 stop bit.
- RX: DMA2 Stream2 circular mode, 128바이트 버퍼.

### L298N

| 기능 | STM32 핀 | 역할 |
|---|---|---|
| ENA | PA0 / TIM2 CH1 | 왼쪽 모터 그룹 PWM |
| IN1 | PC0 | 왼쪽 방향 |
| IN2 | PC1 | 왼쪽 방향 |
| ENB | PA1 / TIM2 CH2 | 오른쪽 모터 그룹 PWM |
| IN3 | PC2 | 오른쪽 방향 |
| IN4 | PC3 | 오른쪽 방향 |

- TIM2: Prescaler 4, Auto-reload 999, 20 kHz.
- 초기 PWM과 방향 GPIO는 모두 0.
- 좌우 전진 GPIO 극성은 실제 L298N·모터 배선에 맞춰 적용되어 있습니다.

### 디버깅과 예비 핀

| 기능 | 핀 |
|---|---|
| SWD | PA13, PA14 |
| 예비 | PA2, PA3 |

최종 필드 펌웨어는 USART2와 PC Teleplot 출력을 사용하지 않습니다. PID·IMU 상태는
Bluetooth 상태 패킷으로 앱에 표시합니다.

## 6. 펌웨어 구성

### 기술 스택

- STM32CubeMX 생성 프로젝트.
- STM32 HAL Driver.
- FreeRTOS CMSIS-RTOS2.
- C11 애플리케이션 코드.
- CMake 3.22 이상과 Ninja.
- GCC Arm Embedded toolchain.

### 클록과 주변장치

| 항목 | 설정 |
|---|---|
| HSE | NUCLEO 8 MHz bypass clock source |
| SYSCLK / HCLK | 100 MHz / 100 MHz |
| PCLK1 / PCLK2 | 50 MHz / 100 MHz |
| I2C1 / I2C3 | 각각 100 kHz |
| TIM2 | 20 kHz 모터 PWM |
| PCA9685 | 50 Hz 서보 PWM |
| USART1 | 9600 baud, 8-N-1 |

### 애플리케이션 라이브러리

| 모듈 | 역할 |
|---|---|
| `bluetooth` | DMA 수신, 16바이트 파싱, 검증, ACK·상태 전송 |
| `servo_driver` | PCA9685 초기화와 채널 PWM 출력 |
| `robot_arm` | 6채널 자세, 보정, S-curve, 티칭 재생 |
| `drive_4wd` | L298N PWM·방향, 타임아웃, 인터록, Yaw PID |
| `teaching_storage` | 시퀀스·설정의 Sector 7 저장과 검증 |
| `imu` | MPU6050 초기화, 보정, 필터, 상대 Yaw |

의존 관계는 다음과 같습니다.

```text
BluetoothTask ── bluetooth ── USART1 DMA
ArmTask ─────── robot_arm ─── servo_driver ── I2C1/PCA9685
ArmTask ─────── teaching_storage ───────────── 내부 Flash
DriveTask ───── drive_4wd ─────────────────── TIM2/GPIO/L298N
ImuTask ─────── imu ───────────────────────── I2C3/MPU6050
StatusTask ──── bluetooth ─────────────────── PID·IMU 상태 송신
```

### FreeRTOS 구조

| 태스크 | 우선순위 | 스택 | 역할 |
|---|---|---:|---|
| `bluetoothTask` | AboveNormal | 384 words | DMA 데이터 파싱과 큐 전달 |
| `armTask` | Normal | 384 words | 로봇팔, 티칭, 설정, Flash |
| `driveTask` | High | 256 words | 차량 제어와 타임아웃 검사 |
| `imuTask` | BelowNormal | 512 words | MPU6050 보정과 20 ms 측정 |
| `statusTask` | Low | 256 words | PID·IMU 상태 전송 |

| RTOS 객체 | 설정 | 용도 |
|---|---:|---|
| `armQueue` | 길이 8 | 로봇팔·티칭·설정 명령 |
| `driveQueue` | 길이 4 | 차량 명령 |
| `i2cMutex` | Mutex | PCA9685 I2C1 직렬화 |
| `imuI2cMutex` | Mutex | MPU6050 I2C3 직렬화 |
| `flashMutex` | Mutex | Sector 7 삭제·기록 직렬화 |

ISR에서는 패킷 파싱, 장치 제어, Mutex 획득과 Flash 작업을 하지 않습니다.
UART 오류 콜백은 플래그만 기록하고 BluetoothTask가 DMA를 재시작합니다.

### 부팅 순서

1. 차량 GPIO와 PWM을 0으로 초기화.
2. E-STOP 잠금과 서보 출력 OFF 유지.
3. RTOS Queue, Mutex와 Task 생성.
4. Sector 7의 티칭·PID·서보 보정값 읽기.
5. PCA9685 초기화. 실패하면 로봇팔만 비활성화하고 1초마다 재시도.
6. MPU6050 확인. 연결되면 차량을 정지하고 3초 영점 보정.
7. 앱 연결과 사용자의 STOP 해제·로봇팔 활성화 대기.

저장된 자세나 티칭 시퀀스를 부팅 직후 자동 재생하지 않습니다.

## 7. 로봇팔 제어

### 앱 표시와 내부 값

| 대상 | 앱 표시 | 패킷·Flash |
|---|---|---|
| Base~Wrist Rotate | `-90~+90°` | `0~180` |
| Gripper | 열림 `0%`~닫힘 `100%` | `0~180` |
| 속도 | `50~100%` | `50~100` |

일반 서보에는 위치 피드백이 없습니다. 앱과 펌웨어가 표시하는 위치는 실제 측정값이
아니라 마지막으로 요청한 위치입니다.

### 원점과 이동 자세

- 원점: 다섯 관절 `0°`, Gripper 완전 열림 `0%`.
- 원점 패킷: `[90,90,90,90,90,0]`.
- 이동 자세: 티칭 시퀀스 9.
- 이동 자세 실행 시 현재 Gripper 위치 유지.
- Gripper를 여는 동작은 사용자가 `원점으로 이동`을 명시적으로 요청한 경우만 수행.

### 이동 방식

- PCA9685 갱신 주기에 맞춘 20 ms 제어 주기.
- 5차 S-curve를 이용해 느리게 출발하고, 중간에 가속한 뒤, 목표에서 감속.
- 앱에서 `50~100%` 속도 선택. `100%`의 각속도 상한은 약 `62.5°/s`.
- 이동 시간은 20 ms부터 25%씩 늘려 6개 관절의 속도·가속도·저크 제한을
  모두 만족하는 가장 짧은 후보로 자동 결정.
- 이동 중 목표나 속도가 변해도 현재 위치·속도·가속도를 이어서 재계획.
- 목표 도착 뒤 Transaction ID를 포함한 ACK 전송.
- 시퀀스 완료 ACK 뒤 마지막 명령 자세를 앱 수동 제어 화면에 반영.
- Flash 시퀀스의 마지막 자세 조회부터 재생 완료까지 중복 요청을 잠그며, 조회
  실패 시 실제 재생을 시작하지 않음.
- 첫 출력 활성화는 실제 시작 위치를 모르므로 설정 속도를 보장할 수 없음.

### 방향 설정

| 관절 | 출력 방향 |
|---|---|
| Base | 반전 |
| Shoulder | 반전 |
| Elbow | 기본 |
| Wrist Tilt | 반전 |
| Wrist Rotate | 반전 |
| Gripper | 반전 |

### 서보 안전 초기값

Sector 7에 유효한 보정값이 없을 때만 사용합니다. 실측 끝점이 아닙니다.

| 채널 | 관절 | -90°/열림 | 중앙 | +90°/닫힘 |
|---:|---|---:|---:|---:|
| 0 | Base | 2300 µs | 1500 µs | 700 µs |
| 1 | Shoulder | 2300 µs | 1500 µs | 700 µs |
| 2 | Elbow | 700 µs | 1500 µs | 2300 µs |
| 3 | Wrist Tilt | 2300 µs | 1500 µs | 700 µs |
| 4 | Wrist Rotate | 2300 µs | 1500 µs | 700 µs |
| 5 | Gripper | 1800 µs | 1500 µs | 1200 µs |

### 실측 보정값

| 채널 | 관절 | -90° | 0° | +90° | 상태 |
|---:|---|---:|---:|---:|---|
| 0 | Base | 2500 | 1500 | 500 | 측정 완료 |
| 1 | Shoulder | 2322 | 1466 | 633 | 측정 완료 |
| 2 | Elbow | 633 | 1500 | 2388 | 측정 완료 |
| 3 | Wrist Tilt | 2500 | 1500 | 500 | 임시값 |
| 4 | Wrist Rotate | 2533 | 1500 | 500 | 측정 완료 |

단위는 µs입니다. Wrist Tilt 끝점은 실기 확인이 필요합니다.

| Gripper 상태 | 앱 | 패킷 | 실측 펄스 |
|---|---:|---:|---:|
| 최대 열림 | 0% | 0 | 1840 µs |
| 중간 | 50% | 90 | 1490 µs |
| 최대 닫힘 | 100% | 180 | 1140 µs |

### 앱 원점 보정 절차

1. 원점 보정 화면 진입.
2. 전체 원점 이동과 도착 ACK 확인.
3. Base부터 Gripper까지 관절 선택.
4. 일반 관절 `-90/0/+90°`, Gripper 열림·닫힘 펄스 조정.
5. 확인 시퀀스로 끝점과 중앙 확인.
6. 저장 버튼으로 Sector 7에 기록.

| 대상 | 앱 조정 범위 |
|---|---:|
| 일반 관절 | `350~2650 µs` |
| Gripper | `1000~2000 µs` |

Gripper 중앙값은 열림과 닫힘의 평균으로 자동 계산합니다. 미리보기 중 선택한 관절만
움직이고 다른 관절은 원점을 유지합니다. 최신 목표 도착 ACK 전에는 관절 전환이나
저장을 허용하지 않습니다.

## 8. 차량 제어

### 구동 방식

- 왼쪽 모터 2개를 한 그룹, 오른쪽 모터 2개를 한 그룹으로 제어.
- 좌우 PWM 차이로 전진, 후진, 회전과 곡선 주행 구현.
- 앱 조이스틱 PWM `0~220`을 전송하고 펌웨어가 `0~255` 범위에서 PID 보정.
- 앱이 조이스틱 입력 중 약 100 ms마다 최신 명령 전송.
- PWM이 0이면 해당 모터 그룹 정지.
- 회전 방향 변경 시 한 패킷 동안 중립 정지 후 역방향 적용.
- PID 직진 판정 X축 범위는 앱에서 `0.00~1.00`으로 조정하며 기본값은 `0.10`.
- PID 직진 중에는 판정 범위를 `+0.04` 넓혀 경계에서 반복 전환되지 않게 함.

### 차량 안전 조건

- 부팅 직후 E-STOP 잠금.
- 마지막 유효 차량 명령 후 500 ms가 지나면 자동 정지.
- 앱이 백그라운드로 이동하면 즉시 정지 명령 전송.
- 로봇팔 이동·티칭 재생·원점 보정·Flash 작업·IMU 보정 중 차량 정지.
- 인터록 해제 전에 받은 오래된 주행 패킷 폐기.
- Assert, Stack overflow와 동적 메모리 실패에서 모터 출력 정지.
- 로봇팔 ACK가 10초 동안 없으면 앱이 STOP 요청.

## 9. MPU6050와 상대 Yaw PID

### 센서 처리

1. `WHO_AM_I=0x68` 확인.
2. 가속도 ±2g, 자이로 ±250 dps 설정.
3. 정지 상태에서 3초 자이로 영점 보정.
4. 20 ms마다 센서 읽기.
5. 2 Hz 1차 저역통과 필터 적용.
6. X/Y축 0.30 dps, Z축 0.15 dps deadband 적용.
7. Z축 각속도 적분으로 `-180~+180°` 상대 Yaw 생성.

센서가 연결되지 않아도 수동 차량, 로봇팔과 티칭은 사용할 수 있습니다. 센서가
연속 세 번 실패하면 PID를 끄고 차량을 정지한 뒤 1초마다 재연결합니다.

### 방향 안정화 PID

- 직진·후진 시작 시 현재 Yaw를 목표각으로 저장.
- 좌우 PWM에 PID 보정값을 반대 방향으로 적용.
- 제자리 회전과 곡선 회전에는 적용하지 않음.
- 장착 방향 보정 부호 `-1`, 후진 시 다시 반전.
- 적분항 제한: `±50`.
- 최종 PWM 보정 제한: `±80`.
- 초기 계수: `Kp=2.00`, `Ki=1.40`, `Kd=0.00`.
- 앱 범위: Kp `0.00~2.55`, Ki/Kd `0~100`.
- PID는 부팅 시 자동 활성화하지 않음.
- E-STOP, 정지, 회전, 방향 전환, 통신 타임아웃과 인터록에서 상태 초기화.

MPU6050에는 자력계가 없습니다. 따라서 장시간 누적 오차가 생길 수 있으며 절대
방향을 유지하지 않습니다. 각 직진·후진 구간에서 시작 방향을 유지하는 용도입니다.

## 10. Bluetooth 통신 규격

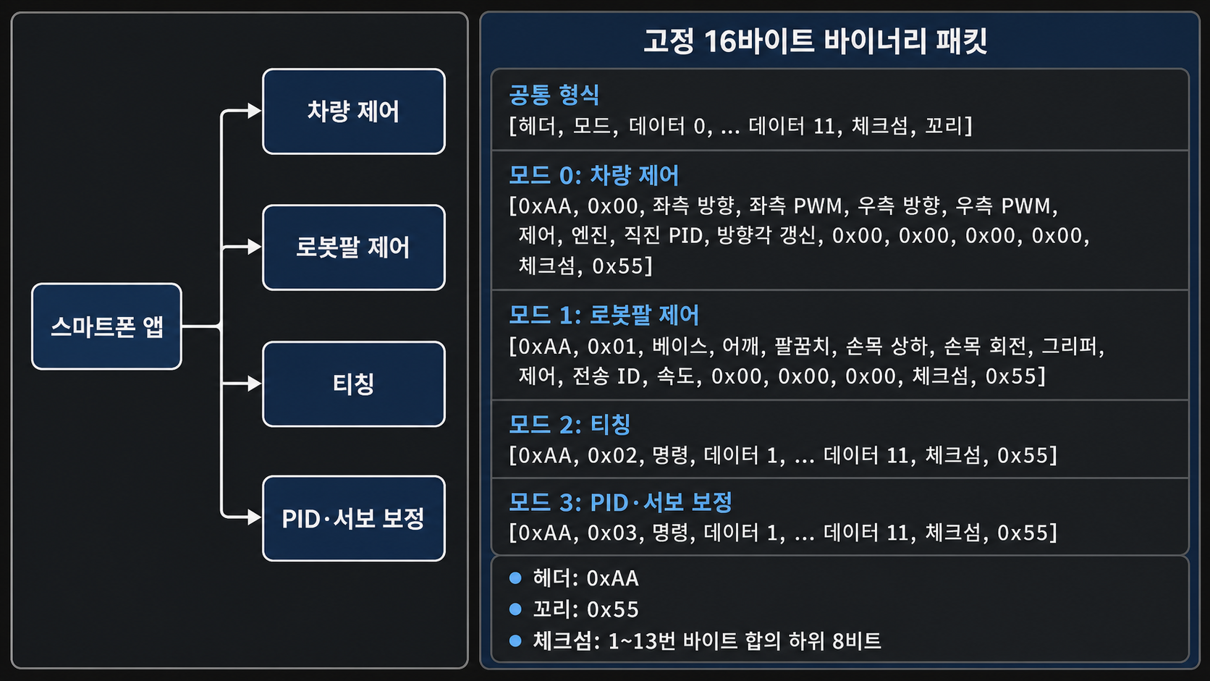
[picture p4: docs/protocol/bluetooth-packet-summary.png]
Bluetooth 16바이트 패킷 요약


### 공통 16바이트 프레임

```text
[Header, Mode, Data0, Data1, ... Data11, Checksum, Tail]
```

| Byte | 내용 |
|---:|---|
| 0 | Header `0xAA` |
| 1 | Mode |
| 2~13 | Data0~Data11 |
| 14 | Byte 1~13 합의 하위 8비트 |
| 15 | Tail `0x55` |

| Mode | 기능 |
|---:|---|
| `0x00` | 차량 제어, E-STOP, PID·IMU 상태 |
| `0x01` | 로봇팔 제어와 출력 상태 |
| `0x02` | 티칭 업로드·조회·재생·초기화 |
| `0x03` | PID·서보 보정 설정 |

ASCII 문자열은 사용하지 않습니다. 명령과 ACK가 같은 고정 길이를 사용하므로 DMA
스트림에서 프레임 경계를 찾고 검증하기 쉽습니다.

### Mode 0: 차량

```text
[AA,00,L_DIR,L_PWM,R_DIR,R_PWM,Control,Engine,PidStraight,RefreshYaw,
 00,00,00,00,Checksum,55]
```

- 방향: `0` 전진, `1` 후진.
- Control: `0` 일반, `1` E-STOP, `2` E-STOP 해제.
- Engine: `0` 정지, `1` 주행.
- PID는 좌우 방향이 같고 PWM이 하나 이상 0보다 클 때만 요청 가능.
- E-STOP과 해제 패킷은 방향·PWM·Engine·PID 필드가 모두 0이어야 함.
- 약 500 ms 간격으로 PID와 IMU 상태를 각각 갱신.

### Mode 1: 로봇팔

```text
[AA,01,Base,Shoulder,Elbow,WristTilt,WristRotate,Gripper,
 Control,TransactionId,Speed,00,00,00,Checksum,55]
```

| Control | 기능 |
|---:|---|
| 0 | 지정 자세로 이동 |
| 1 | 원점으로 이동하며 출력 활성화 |
| 2 | PCA9685 출력 차단 |
| 3 | 시퀀스 9를 현재 Gripper 유지 상태로 실행 |

Transaction ID는 `1~255`, 속도는 `50~100%`입니다. 앱은 요청과 같은 Transaction
ID의 ACK만 완료로 인정합니다.

### Mode 2: 티칭

| Command | 기능 |
|---:|---|
| 2 | Flash 저장 시퀀스 재생 |
| 3 | 선택 시퀀스 초기화 |
| 4 | 이름·웨이포인트 업로드와 COMMIT |
| 5 | 저장 이름 조회 |
| 6 | 저장 웨이포인트 조회 |
| 7 | 현재 편집본 임시 재생 |

업로드는 START → NAME → FIRST → SECOND → COMMIT 순서입니다. 각 웨이포인트는
16바이트 패킷에 맞추기 위해 앞의 세 관절과 뒤의 세 관절로 나눕니다. 모든 이름과
웨이포인트 조각이 도착해야 COMMIT을 허용합니다.

### Mode 3: 설정

| Command | 기능 |
|---:|---|
| 1 | 53바이트 설정 조회 요청 |
| 2 | 설정 조각 업로드 |
| 3 | CRC 확인과 Flash 저장 |
| 4 | 설정 조회 응답 조각 |
| 5 | 서보 펄스 미리보기 |
| 6 | 미리보기 종료 |
| 7 | PID 적용·해제 |

설정은 53바이트를 6개 업로드 조각 또는 7개 조회 조각으로 전달합니다. 저장 전
CRC-16/CCITT-FALSE로 전체 데이터를 검증합니다.

## 11. 티칭 시스템

### 저장 구조

- 총 12개 시퀀스.
- 시퀀스당 최대 30개 웨이포인트.
- 웨이포인트 하나에 Base부터 Gripper까지 6개 목표값 저장.
- 시퀀스 이름은 UTF-8 1~21바이트.

| 시퀀스 | 이름 | 이름 변경 | 용도 |
|---:|---|---|---|
| 1~8 | 사용자 지정 | 가능 | 사용자 동작 |
| 9 | 이동 자세 | 불가 | 차량 주행 준비 |
| 10 | 잡기 위치 | 불가 | 물체 앞 접근 자세 |
| 11 | 잡기 | 불가 | Gripper로 물체 잡기 |
| 12 | 놓기 | 불가 | 물체 놓기 |

고정 시퀀스는 앱에서 잠금 아이콘과 별도 색으로 구분합니다. 펌웨어도 9~12번의
이름 변경을 거부합니다.

### 편집과 재생 원칙

- 로봇팔 화면에서 현재 자세를 웨이포인트로 추가·삭제.
- 티칭 화면에서 각도 직접 입력, 순서 확인, 이름 변경.
- 현재 편집본 재생은 Flash에 쓰지 않고 펌웨어 임시 RAM에서 즉시 실행.
- 다른 시퀀스를 선택하면 미저장 변경을 버리고 Flash 원본을 다시 조회.
- 차량 화면의 시퀀스 9~12 동작은 Flash 저장본 사용.
- 업로드·초기화 중 탭 이동과 데이터 수정 잠금.
- 성공 ACK를 받은 뒤에만 앱 목록과 저장 상태 갱신.
- 부팅 직후 저장 시퀀스를 자동 실행하지 않음.

## 12. Flash 저장

| 항목 | 값 |
|---|---|
| MCU 영역 | 내부 Flash Sector 7 |
| 시작 주소 | `0x08060000` |
| 크기 | 128 KiB |
| 현재 저장 이미지 | 2,516바이트 |
| 애플리케이션 FLASH 제한 | 384 KiB |
| 저장 형식 | 버전 8 |
| 무결성 | 이미지 CRC, 설정 CRC, 기록 후 재읽기 검증 |

애플리케이션 링커 영역을 384 KiB로 제한해 Sector 7과 코드가 겹치지 않게 합니다.
기록할 때 Sector 7 전체를 삭제한 뒤 현재 이미지만 앞부분에 씁니다.

### 저장 데이터

- 12개 시퀀스 이름.
- 시퀀스별 웨이포인트 개수와 각도.
- PID Kp, Ki, Kd.
- 6개 서보의 3점 펄스 보정값.
- 이전 버전 호환용 이동 자세 5바이트.
- Magic, 형식 버전과 CRC.

설정 53바이트의 구성은 다음과 같습니다.

| Byte | 데이터 |
|---:|---|
| 0~3 | Kp ×1000, signed int32 LE |
| 4~7 | Ki ×1000, signed int32 LE |
| 8~11 | Kd ×1000, signed int32 LE |
| 12~47 | 서보 6개 × 3점 × uint16 LE |
| 48~52 | 호환용 이동 자세 5바이트 |

- 모든 조각을 RAM에 모은 뒤 COMMIT에서 한 번 저장.
- 기록 뒤 Flash 내용을 다시 읽어 원본과 비교.
- 형식 버전 2~7은 가능한 티칭·설정을 보존해 변환.
- 버전 1은 Gripper 의미가 달라 거부.
- 매 관절 이동마다 Flash를 쓰지 않아 불필요한 마모 방지.
- 저장·초기화 완료 ACK 전에는 전원을 끄면 안 됨.

현재 저장 이미지는 Sector 7 단일 복사본입니다. 삭제·기록 중 전원이 꺼지면 기존
이미지도 무효화될 수 있습니다. 프로젝트 범위에서는 CRC와 재읽기 검증을 사용하며,
상용 수준 전원 장애 복구가 필요하면 A/B 이중 저장이 추가로 필요합니다.

## 13. Flutter 앱

### 기술 구성

| 항목 | 내용 |
|---|---|
| Framework | Flutter |
| Language | Dart, SDK `^3.12.2` |
| 상태 관리 | `provider 6.1.2` |
| Bluetooth | `flutter_classic_bluetooth 0.1.8` |
| 조이스틱 | `flutter_joystick 0.2.2` |
| 대상 | Android, 프로젝트용 직접 설치 |

### 화면 구성

| 화면 | 주요 기능 |
|---|---|
| 차량 | 조이스틱, 전용 시퀀스, PID·직진 판정 범위 설정과 상태 |
| 로봇팔 | 6채널 수동 제어, 속도 설정, 원점 이동·보정 |
| 티칭 | 시퀀스 선택, 이름·웨이포인트 편집, 재생·저장·초기화 |

- 세로 화면은 하단 NavigationBar 사용.
- 가로 화면은 왼쪽 NavigationRail 사용.
- 연결과 STOP은 모든 화면에서 접근 가능.
- 앱을 처음 사용하는 사용자를 위한 단계·상태·실패 메시지 표시.
- 조작 중인 버튼과 완료 ACK를 구분해 중복 요청 방지.
- 업로드나 초기화 중 다른 화면으로 이동하지 못하게 잠금.

### 입력 안전성

- 슬라이더 트랙 탭으로 값이 즉시 점프하지 않음.
- 손잡이 드래그는 300 ms 이상 눌러야 시작.
- `-`/`+` 짧은 입력은 한 단계, 길게 누르면 연속 증가·감소.
- 서보 보정 저장 전 최신 STM32 설정을 다시 읽어 다른 설정 덮어쓰기 방지.
- PID 저장은 차량 화면, 서보 보정은 로봇팔 화면에서만 수행.
- 조이스틱 직진 판정 범위는 앱 실행 중 유지하며 STM32 Flash에는 저장하지 않음.
- 시퀀스 완료 ACK 뒤 마지막 웨이포인트를 수동 제어 화면에 동기화.
- Flash 작업 중 앱 종료·전원 차단 경고 표시.

### 기능 확인 모드

화면 제목을 길게 눌러 Bluetooth 없이 UI와 앱 내부 로직을 시험할 수 있습니다.
기능 확인 모드는 실제 패킷이나 Flash를 변경하지 않으며 실제 연결 중에는 시작할
수 없습니다.

## 14. 시뮬레이터

PyBullet 시뮬레이터는 앱·펌웨어와 같은 관절 순서, 방향과 Mode 1 패킷을 PC에서
확인하는 보조 도구입니다. STM32나 앱과 직접 통신하지 않습니다.

| 항목 | 내용 |
|---|---|
| 언어 | Python |
| 물리 엔진 | PyBullet |
| 모델 | URDF와 STL 메시 |
| 관절 | Base, Shoulder, Elbow, Wrist Tilt, Wrist Rotate, Gripper |
| 검사 | URDF, 질량, 관성, 관절, 패킷과 PID 계산 |

### 활용과 확장

- 링크 질량은 실측값, 링크 길이는 캡처 치수를 5 mm 단위로 정리한 값.
- 무게중심, 관성텐서와 충돌 형상은 관절·패킷 검증용 근사값.
- 기본 중력 0에서 관절 방향, Mode 1 패킷과 PID 계산을 확인.
- 실측 동역학 값을 추가하면 토크·충돌·차량 주행 검증까지 확장 가능.

## 15. 안전 설계

### 소프트웨어 안전

- 부팅 직후 E-STOP 잠금.
- 차량 명령 500 ms 타임아웃.
- 앱 백그라운드 전환 시 즉시 정지.
- E-STOP 한 명령으로 차량과 PCA9685 출력 차단.
- 로봇팔 이동·티칭·설정 중 차량 인터록.
- Flash 작업 중 차량 정지.
- IMU 보정·오류 중 PID 정지.
- 모터 방향 전환 전 중립 구간.
- 패킷 전체 검증과 예약 바이트 검사.
- Transaction ID와 Request ID로 오래된 ACK 무시.
- RTOS 객체 생성 실패, Assert와 Stack overflow에서 안전 정지.

### 하드웨어 운용 안전

1. 전원 연결 전 극성·공통 GND 확인.
2. PCA9685 VCC와 V+ 분리 확인.
3. 서보 전원과 차량 전원 양극 분리 확인.
4. 로봇팔 주변 사람과 장애물 제거.
5. 낮은 부하에서 서보 한 축씩 보정.
6. 기구 걸림, 떨림, 소음 또는 과열 시 즉시 STOP 후 구동 전원 차단.
7. Flash 저장 완료 ACK 전 전원 차단 금지.

현재 BMS, 퓨즈와 물리 비상정지가 없으므로 실험 장비 운용 수준의 주의가
필요합니다.

## 16. 저장소 구조

```text
mobile-retrieval-robot/
├─ app/                         Flutter Android 앱
│  ├─ lib/main.dart             화면과 앱 상태 관리
│  ├─ lib/protocol/             16바이트 패킷 코덱
│  └─ test/                     앱·프로토콜 테스트
├─ firmware/
│  └─ mobile_retrieval_robot/
│     ├─ App/Inc, App/Src       애플리케이션 라이브러리
│     ├─ Core                   CubeMX 생성 코드와 RTOS 연결
│     ├─ Drivers                STM32 HAL
│     ├─ Middlewares            FreeRTOS
│     ├─ cmake                  CubeMX CMake 지원
│     ├─ CMakeLists.txt
│     └─ mobile_retrieval_robot.ioc
├─ simulator/                   PyBullet 보조 시뮬레이터
├─ docs/
│  ├─ hardware/                BOM, 핀맵, 서보, IMU
│  ├─ protocol/                Bluetooth 규격
│  └─ collaboration/           협업 문서
├─ AGENTS.md                    전체 설계·작업 기준
├─ README.md                    저장소 소개
└─ PROJECT_SUMMARY.md           발표용 종합 문서
```

## 17. 빌드와 실행

### Flutter 앱

```powershell
cd app
flutter pub get
flutter run
```

스마트폰 Android 설정에서 HC-05를 먼저 페어링합니다. 앱 실행 후 Bluetooth 권한을
허용하고 페어링된 HC-05를 선택합니다.

### STM32 펌웨어

```powershell
cd firmware/mobile_retrieval_robot
cmake --preset Debug
cmake --build --preset Debug
```

VS Code STM32 확장에서는 `cube-cmake`와 설치된 GCC Arm toolchain을 사용합니다.
생성된 ELF를 ST-LINK/SWD로 NUCLEO-F411RE에 기록합니다.

### 시뮬레이터

```powershell
cd simulator
python -m venv .venv
.\.venv\Scripts\Activate.ps1
python -m pip install -r requirements.txt
python main.py
```

## 18. 사용 순서

1. 모든 신호선, 전원 극성, 공통 GND 확인.
2. 서보용·차량용 외부 전원 인가.
3. STM32 부팅과 MPU6050 3초 보정 대기.
4. Android 설정에서 HC-05 페어링.
5. 앱에서 HC-05 연결.
6. 초기 STOP 잠금 해제.
7. 로봇팔 화면에서 `원점으로 이동` 선택.
8. 실제 원점 도착 확인.
9. 차량 화면 진입 시 이동 자세 시퀀스 9 완료 대기.
10. 차량, 로봇팔 또는 티칭 기능 사용.

## 19. 검증 결과

2026-08-03 기준 전체 검사 결과입니다.

| 검사 | 결과 |
|---|---|
| Flutter 정적 분석 | `flutter analyze` 경고 0개 |
| Flutter 테스트 | 31개 통과 |
| Android Debug APK | 빌드 성공 |
| STM32 Debug CMake | 빌드 성공 |
| 펌웨어 Flash 사용 | 72,272 B / 384 KiB, 약 18.38% |
| 펌웨어 RAM 사용 | 29,032 B / 128 KiB, 약 22.15% |
| 시뮬레이터 단위 테스트 | 13개 통과 |
| PyBullet URDF DIRECT 로딩 | 성공 |
| Markdown 링크 검사 | 통과 |

`flutter_classic_bluetooth 0.1.8`은 현재 빌드되지만 Flutter의 미래 Kotlin Gradle
처리 방식과 관련한 경고가 있습니다. 현재 프로젝트 실행에는 영향이 없으며 Flutter
메이저 업데이트 전에 대체 플러그인의 실기기 검증이 필요합니다.

## 20. 현재 구현과 발전 방향

### 구현 완료

- 앱·펌웨어 고정 16바이트 프로토콜 일치.
- 4WD 수동 주행, 정지와 통신 타임아웃.
- 6채널 로봇팔 수동 제어와 S-curve.
- 원점 보정과 Flash 저장.
- 이름 포함 티칭 시퀀스 편집·저장·재생·초기화.
- 이동 자세·잡기 위치·잡기·놓기 전용 시퀀스.
- MPU6050 측정과 상대 Yaw PID.
- 주요 차량·로봇팔 상호 인터록.
- Flutter UI, 오류 안내와 기능 확인 모드.

### 실물 적용 완료

- XL4015 서보 전원과 STM32 VIN용 DC-DC 배선.
- MPU6050 VCC, I2C 배선과 실제 장착 방향.
- MPU6050 장착 방향을 반영한 펌웨어 PID 보정 부호 `-1`.
- L298N 좌우 전진 GPIO 극성과 모터 배선.

구체적인 전원 출력 측정값은 저장소 문서에 아직 숫자로 기록되지 않았습니다.
확인되지 않은 숫자를 이 문서에서 추정하지 않습니다.

### 완성도 향상

- Wrist Tilt 실제 안전 끝점.
- 실제 차체에서 PID 계수 조정.
- 로봇팔을 펼친 상태에서 허용할 차량 속도.

### 발전 가능성

- 위치 피드백 서보를 적용한 관절 폐루프 제어.
- 절대 방향 센서를 결합한 장시간 Yaw 보정.
- 휠 엔코더를 이용한 속도·거리 제어.
- 이중 저장이나 저널링을 이용한 Flash 복구 강화.
- 물리 비상정지와 전원 보호 회로 추가.
- 실측 질량·관성을 반영한 차량·로봇팔 동역학 시뮬레이션.

## 21. 발표 시연 권장 순서

1. 전체 하드웨어와 전원 분리 구조 설명.
2. 앱에서 HC-05 연결과 초기 STOP 잠금 확인.
3. 원점 이동과 부드러운 S-curve 시연.
4. 로봇팔 수동 제어와 Gripper 열기·닫기 시연.
5. 티칭에서 사용자 시퀀스 이름과 웨이포인트 생성.
6. Flash 저장 후 현재 편집본과 저장본 재생 차이 설명.
7. 이동 자세 → 잡기 위치 → 잡기 → 차량 이동 → 놓기 시연.
8. PID 적용 전후 직진 차이와 앱의 Yaw·PWM 상태 표시.
9. 통신 중단 또는 STOP으로 안전 정지 확인.

## 22. 발표 핵심 기술 포인트

1. **통합 제어**: 차량, 로봇팔, 티칭과 PID를 하나의 Flutter 앱에서 관리.
2. **신뢰성 있는 통신**: 고정 16바이트, Checksum, 범위 검사, 스트림 재동기화,
   Transaction ID와 ACK 사용.
3. **실물 대응 보정**: 관절마다 다른 방향과 펄스 끝점을 앱에서 직접 3점 보정.
4. **부드러운 동작**: 20 ms 온라인 S-curve로 급격한 서보 이동 완화.
5. **안전 인터록**: 로봇팔 작업 중 차량 정지, 통신 타임아웃과 E-STOP 적용.
6. **사용자 티칭**: 코드를 수정하지 않고 이름과 자세 시퀀스를 Flash에 저장.
7. **센서 융합 확장**: MPU6050 상대 Yaw를 이용해 엔코더 없이 직진 방향 보조.
8. **역할 분리**: DMA 수신, RTOS Task, Queue, Mutex와 모듈형 펌웨어 구성.

## 23. 참고 문서

- 저장소 소개: [README.md](README.md)
- 앱: [app/README.md](app/README.md)
- 펌웨어: [firmware/README.md](firmware/README.md)
- 시뮬레이터: [simulator/README.md](simulator/README.md)
- 부품: [docs/hardware/bom.md](docs/hardware/bom.md)
- 핀맵: [docs/hardware/pin-map.md](docs/hardware/pin-map.md)
- PCA9685·S-curve: [docs/hardware/servo-control.md](docs/hardware/servo-control.md)
- 서보 보정: [docs/hardware/servo-calibration.md](docs/hardware/servo-calibration.md)
- IMU: [docs/hardware/imu.md](docs/hardware/imu.md)
- 상대 Yaw PID: [docs/hardware/yaw-pid.md](docs/hardware/yaw-pid.md)
- Bluetooth: [docs/protocol/bluetooth-protocol.md](docs/protocol/bluetooth-protocol.md)

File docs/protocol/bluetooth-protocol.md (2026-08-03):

# Bluetooth 16바이트 프로토콜

Flutter 앱과 STM32 펌웨어의 기준 규격입니다.

- UART: 9600 baud, 8-N-1.
- 고정 16바이트 바이너리. ASCII 명령은 사용하지 않음.
- 구현: `app/lib/protocol/robot_packet.dart`,
  `firmware/mobile_retrieval_robot/App/Src/bluetooth.c`.

## 통합 통신 프로토콜 요약

Bluetooth 16바이트 패킷 요약

고정 16바이트 바이너리 패킷을 사용합니다.

```text
공통 형식
[헤더, 모드, 데이터 0, ... 데이터 11, 체크섬, 꼬리]

모드 0: 차량 제어
[0xAA, 0x00, 좌측 방향, 좌측 PWM, 우측 방향, 우측 PWM,
 제어, 엔진, 직진 PID, 방향각 갱신, 0x00, 0x00, 0x00, 0x00,
 체크섬, 0x55]

모드 1: 로봇팔 제어
[0xAA, 0x01, 베이스, 어깨, 팔꿈치, 손목 상하, 손목 회전, 그리퍼,
 제어, 전송 ID, 속도, 0x00, 0x00, 0x00, 체크섬, 0x55]

모드 2: 티칭
[0xAA, 0x02, 명령, 데이터 1, ... 데이터 11, 체크섬, 0x55]

모드 3: PID·서보 보정
[0xAA, 0x03, 명령, 데이터 1, ... 데이터 11, 체크섬, 0x55]
```

- 헤더: `0xAA`
- 꼬리: `0x55`
- 체크섬: 1~13번 바이트 합의 하위 8비트

## 공통 프레임

```text
[Header, Mode, Data0, ... Data11, Checksum, Tail]
```

| Byte | 값 |
|---:|---|
| 0 | Header `0xAA` |
| 1 | Mode: `0` Drive, `1` Arm, `2` Teaching, `3` Settings |
| 2~13 | Data0~Data11 |
| 14 | Byte 1~13 합의 하위 8비트 |
| 15 | Tail `0x55` |

Header, Tail, Mode, Checksum 또는 Mode별 범위가 틀리면 전체 프레임을 폐기합니다.

## Mode 0: Drive

```text
[AA,00,L_DIR,L_PWM,R_DIR,R_PWM,Control,Engine,PidStraight,RefreshYaw,
 00,00,00,00,checksum,55]
```

| 필드 | 값 |
|---|---|
| `L_DIR`, `R_DIR` | `0` 전진, `1` 후진 |
| `L_PWM`, `R_PWM` | `0~255` |
| `Control` | `0` 일반, `1` E-STOP, `2` E-STOP 해제 |
| `Engine` | `0` 정지, `1` 주행 |
| `PidStraight` | `0/1` 상대 Yaw PID 요청 |
| `RefreshYaw` | `0/1` 현재 Yaw를 목표로 갱신 |

검증:

- Data8~Data11은 `0`.
- `Engine=0`이면 PWM과 PID 필드도 `0`.
- PID는 좌우 방향이 같고 PWM이 하나 이상 0보다 클 때만 허용.
- `RefreshYaw=1`은 `PidStraight=1`일 때만 허용.
- E-STOP 설정·해제 프레임의 방향, PWM, Engine과 PID 필드는 `0`.

앱은 주행 중 약 100 ms마다 전송합니다. 펌웨어는 500 ms 동안 유효한 명령이
없거나 다른 Mode로 바뀌면 정지합니다. 역전은 한 프레임의 중립 정지 뒤
적용합니다. 인터록 해제 전 프레임은 재사용하지 않습니다.

앱은 PID 보정 여유를 남기기 위해 조이스틱 출력을 최대 `220 PWM`으로 제한합니다.
`PidStraight`는 앱의 X축 직진 판정 범위로 결정하며 기본값은 `0.10`, PID 유지
중에는 `+0.04` 히스테리시스를 사용합니다. 이 값은 앱 내부 설정이므로 패킷과
STM32 Flash에는 포함하지 않습니다.

### E-STOP ACK

```text
[AA,00,Control,Status,Reason,00,00,00,00,00,00,00,00,00,checksum,55]
```

앱은 해제 ACK의 `Status=1`을 받은 뒤 잠금을 해제합니다.

### PID·IMU 상태

250 ms마다 두 종류를 번갈아 보내며 각 종류는 약 500 ms마다 갱신됩니다.

```text
PID: [AA,00,03,Flags,TargetYawL,TargetYawH,CurrentYawL,CurrentYawH,
      ErrorL,ErrorH,OutputL,OutputH,LeftPwm,RightPwm,checksum,55]
IMU: [AA,00,04,Flags,TempL,TempH,GyroZL,GyroZH,YawL,YawH,
      ErrorCount0,ErrorCount1,ErrorCount2,ErrorCount3,checksum,55]
```

- PID Flags: bit0 명령, bit1 PID 활성, bit2 연산 중, bit3 후진,
  bit4 목표 갱신, bit5 IMU 사용 가능.
- PID 각도·출력: signed int16 little-endian, ×100.
- PWM: 실제 적용된 `0~255`.
- IMU Flags: bit0 초기화, bit1 보정, bit2 최신값 유효.
- 온도·Gyro Z·Yaw: signed int16 little-endian, ×100.
- 오류 횟수: unsigned int32 little-endian.

앱은 1.5초 이상 갱신되지 않은 상태를 오래된 값으로 처리합니다.

## Mode 1: Arm

```text
[AA,01,Base,Shoulder,Elbow,WristTilt,WristRotate,Gripper,
 Control,TransactionId,Speed,00,00,00,checksum,55]
```

| Data | 값 |
|---:|---|
| 0~4 | 앱 각도 `-90~+90°`에 90을 더한 `0~180` |
| 5 | Gripper `0~100%`를 변환한 `0~180` |
| 6 | `0` 이동, `1` 원점 활성화, `2` 출력 차단, `3` 시퀀스 9 |
| 7 | Transaction ID `1~255` |
| 8 | 속도 `50~100%` |
| 9~11 | `0` |

규칙:

- 원점: `[90,90,90,90,90,0]`.
- `Control=3`: Data0~Data5는 `0`; Flash 시퀀스 9를 현재 Gripper 유지 상태로 재생.
- 출력 활성화 전 이동 거부.
- 한 관절이라도 범위를 벗어나면 전체 자세 거부.
- 수동 명령은 티칭 재생 중지.
- 이동·재생 중 차량 인터록.
- 위치는 실측값이 아니라 마지막 명령값.

### ACK

```text
[AA,01,Command,Status,Reason,TransactionId,00,00,00,00,00,00,00,00,
 checksum,55]
```

| Reason | 의미 |
|---:|---|
| 0 | 성공 |
| 1 | 값 오류 |
| 2 | 미보정 관절 |
| 3 | 출력 비활성 |
| 4 | 다른 동작 중 |
| 5 | PCA9685 오류 |
| 6 | 성공했지만 설정 속도 보장 불가 |

일반 이동 성공 ACK는 목표 도착 후 보냅니다. 앱은 같은 Transaction ID만
완료로 인정하며 10초 안에 응답이 없으면 E-STOP을 요청합니다.

## Mode 2: Teaching

12개 시퀀스, 시퀀스당 최대 30개 웨이포인트를 사용합니다.

| 시퀀스 | 이름 | 변경 |
|---:|---|---|
| 1~8 | 사용자 지정 | 가능 |
| 9 | 이동 자세 | 불가 |
| 10 | 잡기 위치 | 불가 |
| 11 | 잡기 | 불가 |
| 12 | 놓기 | 불가 |

이름은 UTF-8 `1~21`바이트입니다. 앱은 9~12번을 잠금 아이콘과 용도별 색으로
구분하며 펌웨어도 고정 이름이 아니면 업로드를 거부합니다.

### 재생

```text
요청: [AA,02,02,Sequence,Speed,00,00,00,00,00,00,00,00,00,checksum,55]
응답: [AA,02,02,Sequence,Status,SpeedWarning,00,00,00,00,00,00,00,00,
       checksum,55]
```

- Sequence `1~12`, Speed `50~100`.
- 빈 시퀀스와 중복 재생은 거부.
- 부팅 시 자동 재생하지 않음.
- `SpeedWarning=1`은 안전 재계획으로 일부 구간의 설정 속도를 보장하지 못함.
- 앱은 성공 응답 뒤 저장 시퀀스의 마지막 웨이포인트를 수동 제어 화면에 반영.
- 앱은 마지막 웨이포인트 조회부터 작업을 잠그고 조회 실패 시 재생 요청을 보내지 않음.

### 초기화

```text
요청: [AA,02,03,Sequence,00,00,00,00,00,00,00,00,00,00,checksum,55]
응답: [AA,02,03,Sequence,Status,00,00,00,00,00,00,00,00,00,checksum,55]
```

RAM과 Flash를 비우며 앱은 `Status=1`에서만 목록을 삭제합니다.

### 업로드

```text
START:  [AA,02,04,01,Sequence,Count,NameLength,00,00,00,00,00,00,00,
         checksum,55]
NAME:   [AA,02,04,05,Sequence,Part,N0,N1,N2,N3,N4,N5,N6,N7,checksum,55]
FIRST:  [AA,02,04,02,Sequence,Index,A0,A1,A2,00,00,00,00,00,checksum,55]
SECOND: [AA,02,04,03,Sequence,Index,A3,A4,A5,00,00,00,00,00,checksum,55]
COMMIT: [AA,02,04,04,Sequence,00,00,00,00,00,00,00,00,00,checksum,55]
ACK:    [AA,02,04,Sequence,Status,00,00,00,00,00,00,00,00,00,checksum,55]
```

- Count `1~30`, Index `0~Count-1`.
- NameLength `1~21`, Part `0~2`; NAME은 8바이트씩 보내고 남는 바이트는 `0`.
- A0~A4는 관절 `0~180`, A5는 Gripper `0~180`.
- 모든 NAME·FIRST·SECOND 조각이 있어야 COMMIT 허용.
- Sector 7 기록 후 전체 내용을 다시 비교.

업로드·재생·초기화 중 앱은 화면 전환과 관련 데이터 수정을 잠급니다.

### 편집본 임시 재생

앱은 START·NAME·FIRST·SECOND로 현재 편집본을 임시 버퍼에 보낸 뒤 COMMIT 대신
다음 명령을 전송합니다.

```text
요청: [AA,02,07,Sequence,Speed,00,00,00,00,00,00,00,00,00,checksum,55]
응답: Mode 2 재생 응답과 동일
```

완전한 조각만 재생하며 Sector 7은 변경하지 않습니다. 차량 화면에서 실행하는
시퀀스 9~12는 이 명령이 아닌 Mode 2 재생 명령으로 Flash 저장본을 사용합니다.
앱은 성공 응답 뒤 편집본의 마지막 웨이포인트를 수동 제어 화면에 반영합니다.

### 저장 시퀀스 조회

```text
요청:     [AA,02,06,Sequence,RequestId,00,00,00,00,00,00,00,00,00,
           checksum,55]
메타:     [AA,02,06,Sequence,00,Count,RequestId,00,00,00,00,00,00,00,
           checksum,55]
웨이포인트: [AA,02,06,Sequence,01,Index,A0,A1,A2,A3,A4,A5,RequestId,00,
             checksum,55]
```

앱은 메타와 Count개의 웨이포인트를 모두 받은 경우에만 화면을 바꿉니다. 다른
시퀀스를 선택할 때 미저장 편집본을 버리고 이 조회 결과로 교체합니다.

### 이름 조회

```text
요청: [AA,02,05,Sequence,RequestId,00,00,00,00,00,00,00,00,00,checksum,55]
응답: [AA,02,05,Sequence,Part,NameLength,RequestId,N0,N1,N2,N3,N4,N5,N6,
       checksum,55]
```

응답은 UTF-8 이름을 7바이트씩 전송합니다. 앱은 같은 Sequence, RequestId,
NameLength의 모든 조각을 받은 뒤에만 이름을 갱신합니다.

## Mode 3: Settings

### 53바이트 설정

| Byte | 형식 | 값 |
|---:|---|---|
| 0~3 | int32 LE | Kp ×1000, `0~2550`, 10의 배수 |
| 4~7 | int32 LE | Ki ×1000, `0~100000` |
| 8~11 | int32 LE | Kd ×1000, `0~100000` |
| 12~47 | uint16 LE ×18 | 관절별 `-90/0/+90°` 펄스 |
| 48~52 | uint8 ×5 | 호환용 이동 자세, 실행에는 미사용 |

- 일반 관절 펄스 `350~2650 µs`.
- Gripper 열림·닫힘 `1000~2000 µs`; 중앙은 평균.
- 앱 PID 범위: Kp `0.00~2.55`, Ki/Kd `0~100`.
- 초기 PID: `2.00/1.40/0.00`; 자동 활성화하지 않음.
- 실행 이동 자세는 설정 필드가 아닌 티칭 시퀀스 9.

### 조회

```text
요청: [AA,03,01,RequestId,00,00,00,00,00,00,00,00,00,00,checksum,55]
응답: [AA,03,04,Part,PidApplied,B0,B1,B2,B3,B4,B5,B6,B7,RequestId,
       checksum,55]
```

Part `0~6`. 각 조각은 8바이트이며 마지막 3바이트는 0으로 채웁니다. 앱은 같은
Request ID의 7개 조각을 모두 받아야 값을 갱신합니다.

### 저장

```text
조각: [AA,03,02,Part,B0,B1,B2,B3,B4,B5,B6,B7,B8,B9,checksum,55]
확정: [AA,03,03,53,CrcLow,CrcHigh,00,00,00,00,00,00,00,00,checksum,55]
ACK:  [AA,03,03,Status,Reason,PidApplied,00,00,00,00,00,00,00,00,
       checksum,55]
```

- Part `0~5`; 마지막 조각은 유효 3바이트 뒤를 0으로 채움.
- CRC-16/CCITT-FALSE: init `0xFFFF`, poly `0x1021`.
- 모든 조각과 CRC가 맞아야 기록.

| Reason | 의미 |
|---:|---|
| 0 | 성공 |
| 1 | 조각 누락 |
| 2 | CRC 오류 |
| 3 | 서보 보정·호환 필드 오류 |
| 4 | 로봇팔 동작 중 |
| 5 | Flash 기록·검증 오류 |
| 6 | PID 실행 중 계수 변경 |
| 7 | PID 범위 오류 |

### IMU 영점 보정

```text
요청: [AA,03,08,RequestId,00,00,00,00,00,00,00,00,00,00,checksum,55]
응답: [AA,03,08,Status,Reason,RequestId,00,00,00,00,00,00,00,00,
       checksum,55]
```

- PID 활성화 전에 차량을 정지하고 3초 동안 영점을 다시 측정합니다.
- Reason `0` 성공, `1` IMU 사용 불가, `2` 보정 진행 중, `3` 측정 오류.
- 보정 중 차량 명령은 적용하지 않으며 완료 뒤 새 주행 명령만 사용합니다.

### PID 활성화

```text
요청: [AA,03,07,Enable,RequestId,00,00,00,00,00,00,00,00,00,checksum,55]
응답: [AA,03,07,Status,PidApplied,Reason,RequestId,00,00,00,00,00,00,00,
       checksum,55]
```

- Enable `0/1`.
- Reason `0` 성공, `1` IMU·안전 상태 불가, `2` PID 계수 무효.
- 전환 전 차량 정지.
- 앱은 MPU6050 3초 보정 ACK를 받은 뒤 활성화를 요청.
- E-STOP에서 PID 비활성화.

### 서보 미리보기

```text
요청: [AA,03,05,Joint,PulseLow,PulseHigh,Speed,RequestId,
       00,00,00,00,00,00,checksum,55]
응답: [AA,03,05,Joint,Status,Reason,PulseLow,PulseHigh,RequestId,
       00,00,00,00,00,checksum,55]
종료: [AA,03,06,00,00,00,00,00,00,00,00,00,00,00,checksum,55]
```

- Joint `0~5`, Speed `50~100`, RequestId `1~255`.
- 일반 관절 `350~2650 µs`, Gripper `1000~2000 µs`.
- 선택 관절만 S-curve 이동하고 다른 채널은 원점 유지.
- 최신 Request ID의 도착 ACK 전 선택 변경·저장 금지.
- 목표 도착 후 2초간 새 요청이 없거나 종료 명령을 받으면 미리보기 종료.
- 미리보기 중 차량 인터록. 후보값은 저장 명령 전까지 앱 RAM에만 유지.

## 스트림 처리

USART1 RX는 128바이트 circular DMA입니다.

1. 태스크가 DMA write 위치까지 새 바이트를 읽습니다.
2. `0xAA`부터 16바이트를 모아 전체 검증합니다.
3. 유효 프레임만 제어 큐로 전달합니다.
4. 무효 프레임은 다음 `0xAA`에서 재동기화합니다.
5. UART 오류 콜백은 플래그만 남기고 태스크가 DMA를 재시작합니다.
6. ISR에서는 파싱, 장치 제어와 Flash 작업을 하지 않습니다.

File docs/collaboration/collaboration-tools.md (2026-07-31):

# 협업 도구

| 도구 | 기준 정보 |
|---|---|
| GitHub | 코드, Issue, Pull Request, 핀맵과 프로토콜 |
| Notion | 일정, 담당, 회의, 구매와 시험 이력 |
| Slack | 질문과 당일 소통 |

구현에 적용되는 최종 규격은 GitHub 문서가 기준입니다. 설계나 측정값을 바꾸면
코드와 같은 Pull Request에서 `AGENTS.md`와 관련 `docs/`를 함께 수정합니다.

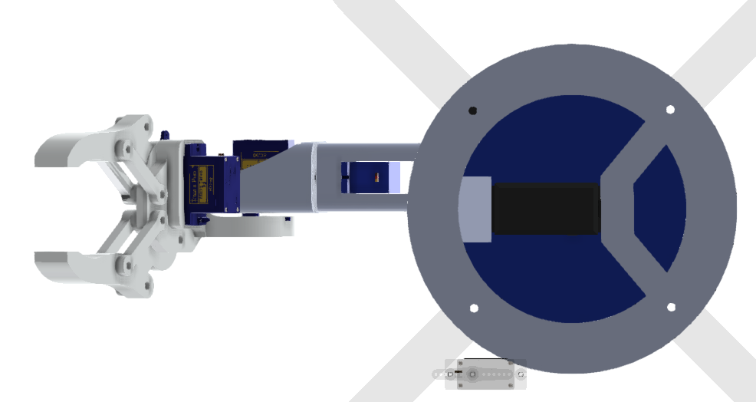
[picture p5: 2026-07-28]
simulator/models/bottom_view.png

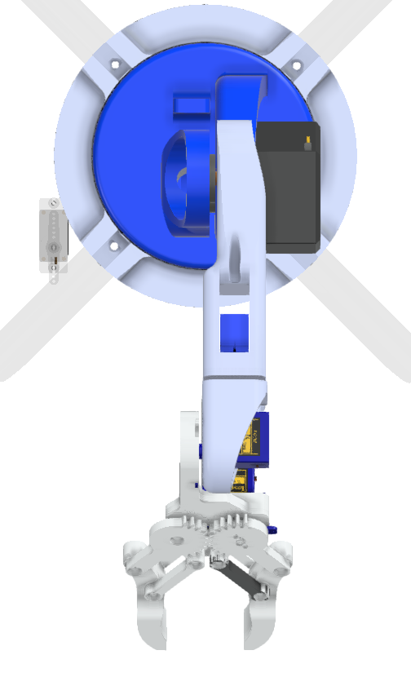
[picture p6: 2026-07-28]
simulator/models/top_view.png

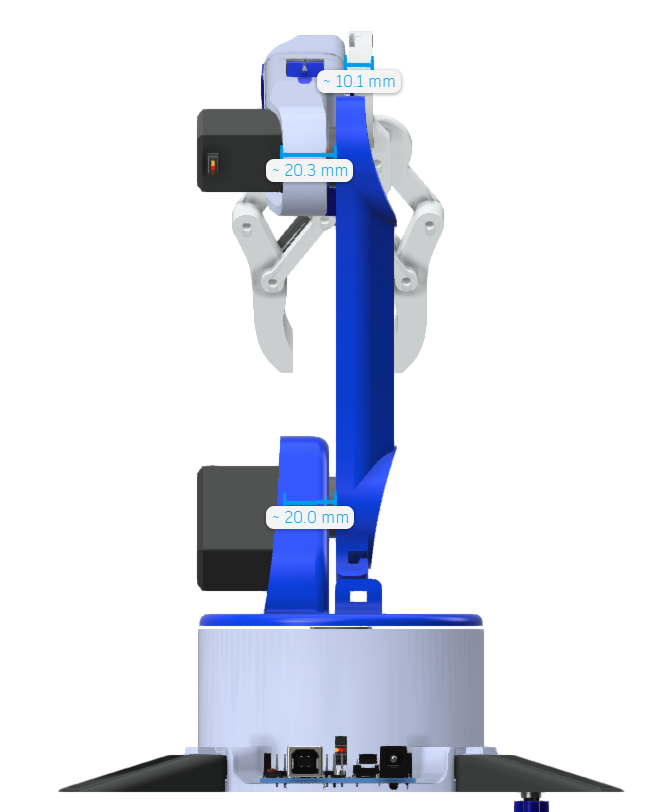
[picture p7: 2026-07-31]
simulator/models/back_view.png

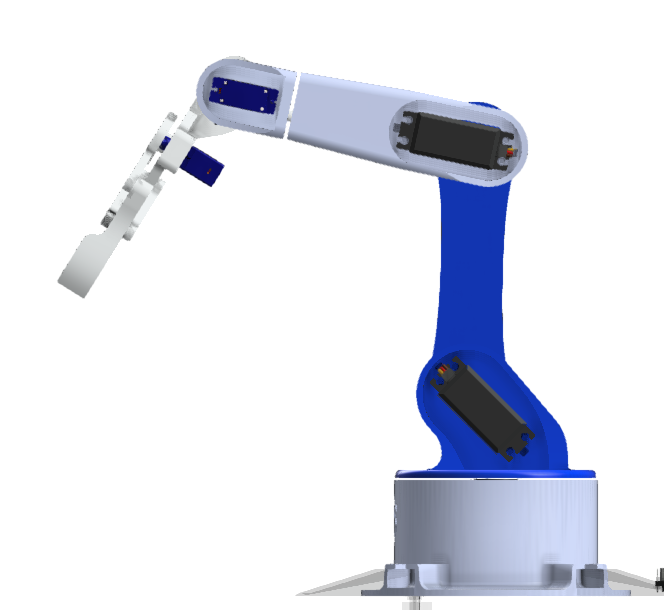
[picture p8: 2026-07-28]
simulator/models/right_side_view.png

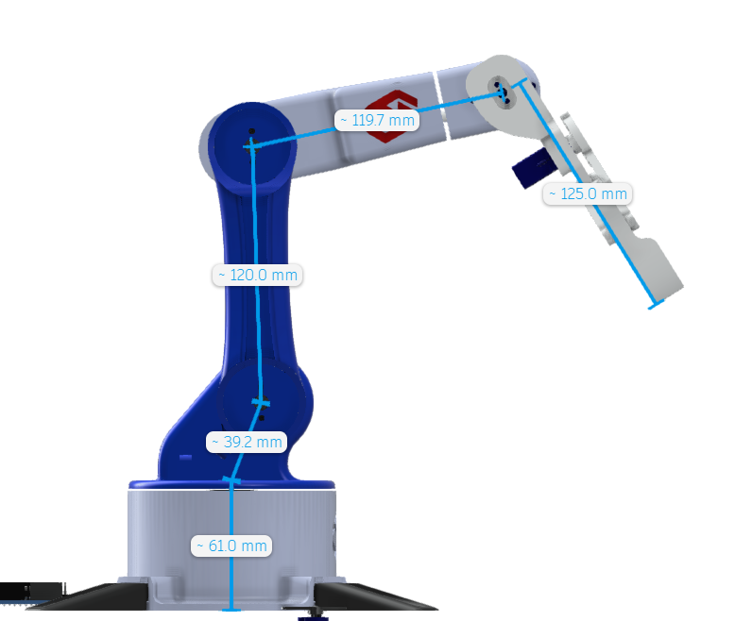
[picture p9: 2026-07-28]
simulator/models/left_side_view.png

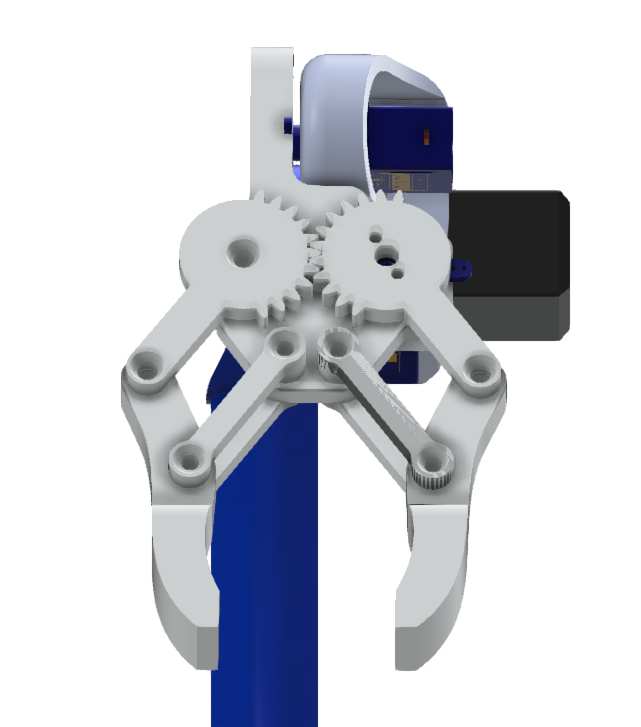
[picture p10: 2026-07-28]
simulator/models/gripper_front_view.png

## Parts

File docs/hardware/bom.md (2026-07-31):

# 부품 목록

배선도에 표시된 실제 부품 기준입니다.

| 구분 | 부품 | 수량 | 용도 |
|---|---|---:|---|
| 제어 | NUCLEO-F411RE | 1 | 전체 제어 |
| 통신 | HC-05 B36 | 1 | Bluetooth Classic SPP |
| 센서 | MPU6050 모듈 | 1 | 가속도·자이로 |
| 서보 드라이버 | PCA9685 | 1 | 50 Hz, 6채널 |
| 고토크 서보 | MG996R | 3 | Base, Shoulder, Elbow |
| 소형 서보 | SG90 | 3 | Wrist Tilt, Wrist Rotate, Gripper |
| 모터 드라이버 | L298N | 1 | 좌우 모터 그룹 |
| 차량 | DC 기어모터·바퀴 | 각 4 | 4WD |
| 배터리 | 18650 | 4 | 독립된 2S 팩 2개 |
| 배터리 홀더 | 2S | 2 | 서보용·차량용 |
| 강압 모듈 | XL4015 | 1 | 서보 전원 |
| 안정화 | 1000 µF 전해 커패시터 | 1 | PCA9685 `V+`–GND |
| 기구 | 3D 출력물·체결 부품 | 1세트 | 로봇팔 |

## 서보 채널

| PCA9685 | 관절 | 서보 |
|---:|---|---|
| 0 | Base | MG996R |
| 1 | Shoulder | MG996R |
| 2 | Elbow | MG996R |
| 3 | Wrist Tilt | SG90 |
| 4 | Wrist Rotate | SG90 |
| 5 | Gripper | SG90 |

## 전원

```text
서보용 2S → XL4015 → PCA9685 V+ → 서보 6개
차량용 2S ─────────→ L298N ─────→ 모터 4개
STM32 논리 전원 ───→ PCA9685 VCC
STM32 VIN DC-DC ───→ 실물 적용(모델·출력 미기록)
```

- 두 팩의 양극은 연결하지 않고 모든 장치의 GND만 공통으로 연결합니다.
- 서보 전류는 XL4015 OUT-, 모터 전류는 차량 배터리 음극으로 직접 귀환합니다.
- 고전류를 STM32 보드와 신호용 점퍼선에 통과시키지 않습니다.
- L298N ENA/ENB 점퍼는 제거하고 PA0/PA1 PWM을 연결합니다.
- BMS, 퓨즈와 물리 비상정지는 현재 구성에 없습니다.
- XL4015, STM32 VIN DC-DC와 MPU6050 전원은 실물에 적용되어 있으며 구체적인 값은 문서에 미기록 상태입니다.

확장 시 장애물 감지 센서, 휠 엔코더와 절대 방향 기준 센서를 추가할 수 있습니다.

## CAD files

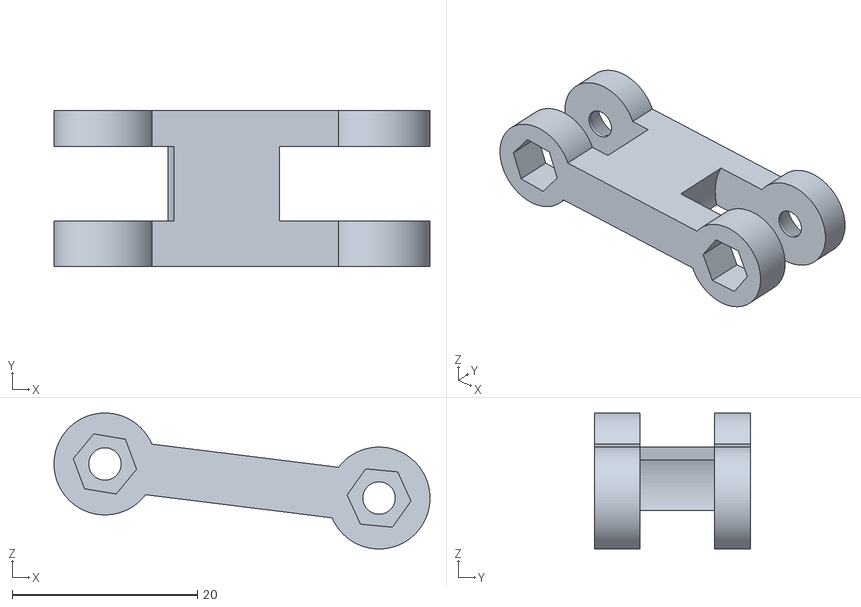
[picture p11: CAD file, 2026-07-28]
simulator/models/bar_2.stl
40.6 x 16.8 x 14.7

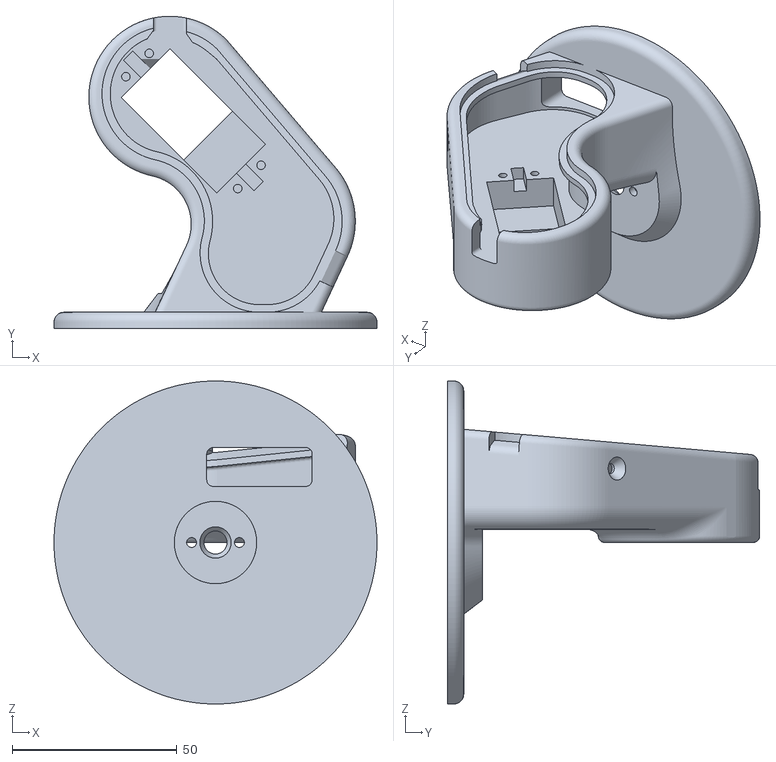
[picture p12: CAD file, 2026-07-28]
simulator/models/central_shaft.stl
98.0 x 94.8 x 98.0

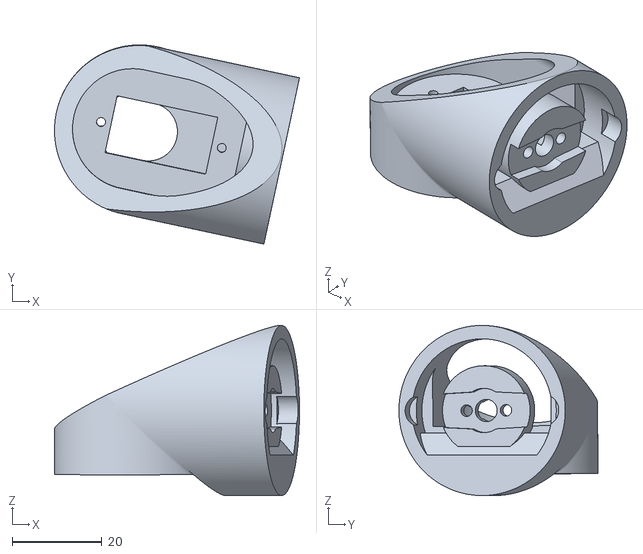
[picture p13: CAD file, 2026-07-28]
simulator/models/wrist.stl
54.8 x 44.5 x 38.0

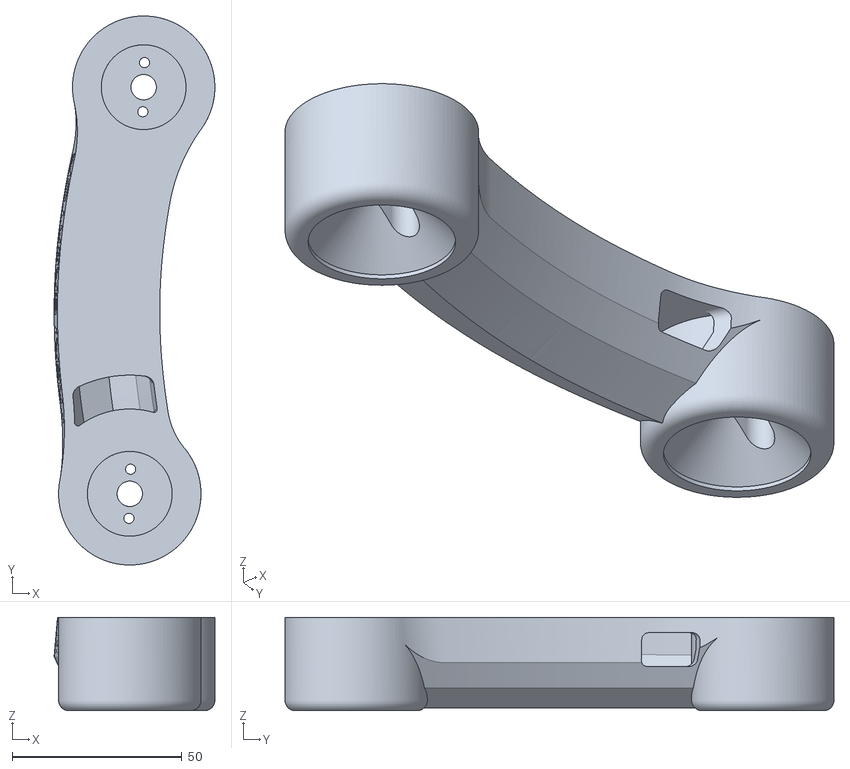
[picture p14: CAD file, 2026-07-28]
simulator/models/forearm.stl
47.4 x 161.9 x 27.5

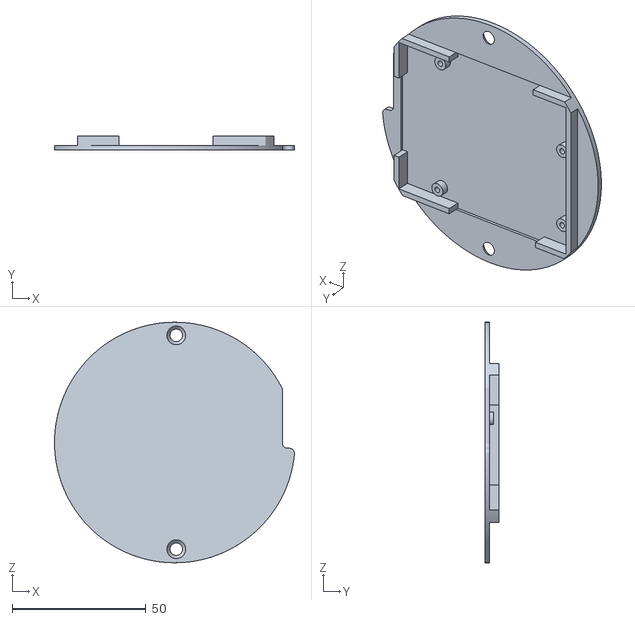
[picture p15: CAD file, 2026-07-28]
simulator/models/base_cover.stl
89.8 x 5.35 x 90.0

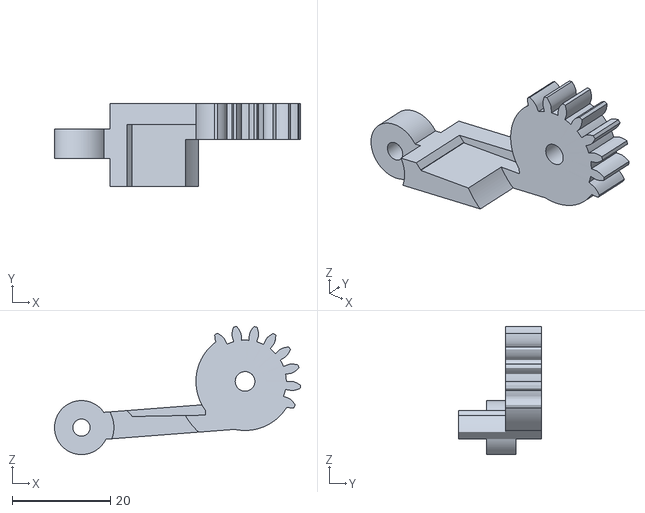
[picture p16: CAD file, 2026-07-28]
simulator/models/gear_1.stl
50.1 x 16.9 x 26.1

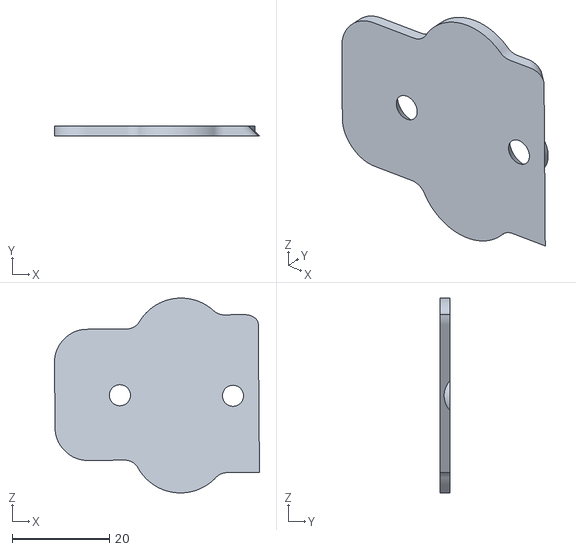
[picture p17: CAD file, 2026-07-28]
simulator/models/gripper_cover.stl
42.2 x 2.00 x 40.1

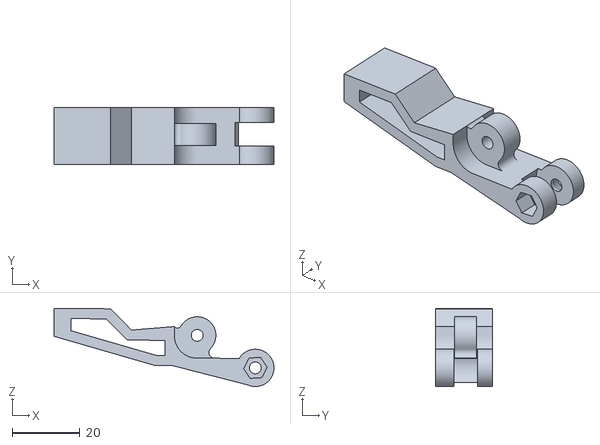
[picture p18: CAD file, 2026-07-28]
simulator/models/gripper_finger_1.stl
64.8 x 16.8 x 23.0

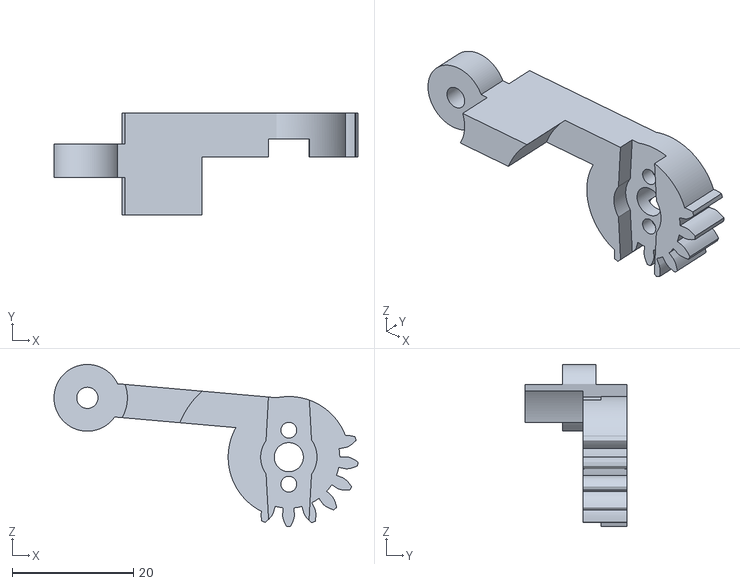
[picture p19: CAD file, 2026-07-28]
simulator/models/gear_2.stl
50.1 x 16.9 x 26.7

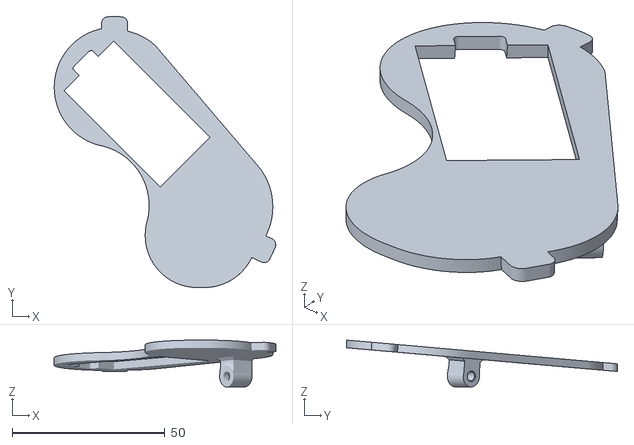
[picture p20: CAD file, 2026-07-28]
simulator/models/shaft_cover.stl
72.5 x 88.7 x 15.3

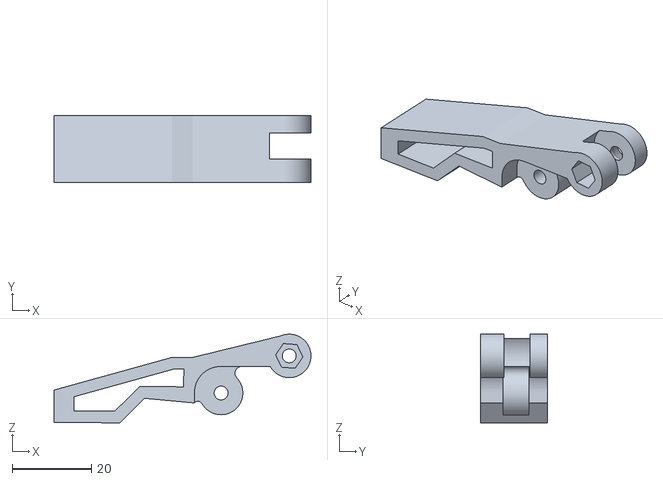
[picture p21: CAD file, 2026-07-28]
simulator/models/gripper_finger_2.stl
65.0 x 16.8 x 22.4

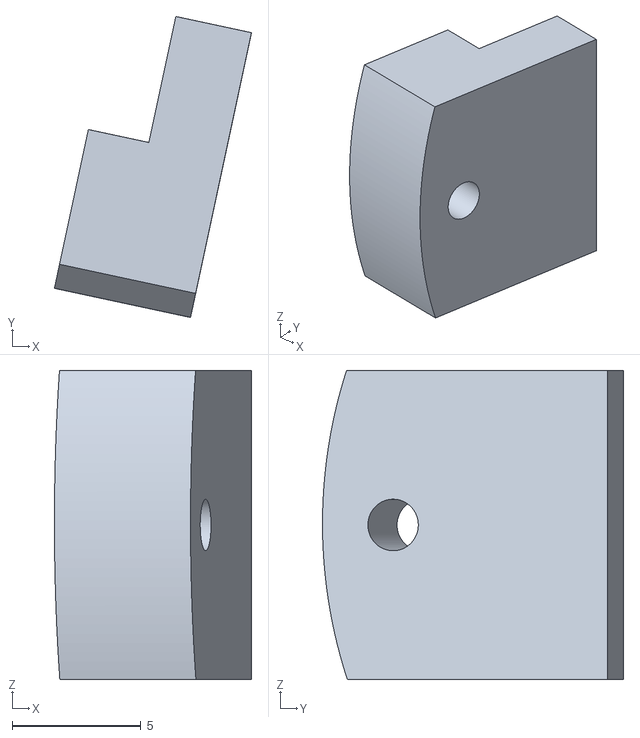
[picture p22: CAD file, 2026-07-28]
simulator/models/servo_retainer.stl
7.65 x 11.7 x 12.0

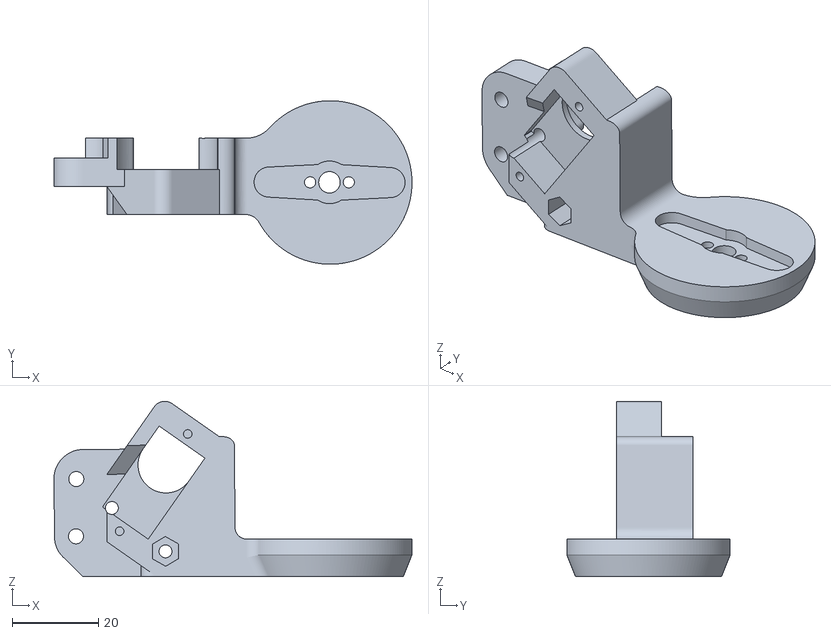
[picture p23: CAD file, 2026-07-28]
simulator/models/gripper_base.stl
83.2 x 38.0 x 40.8

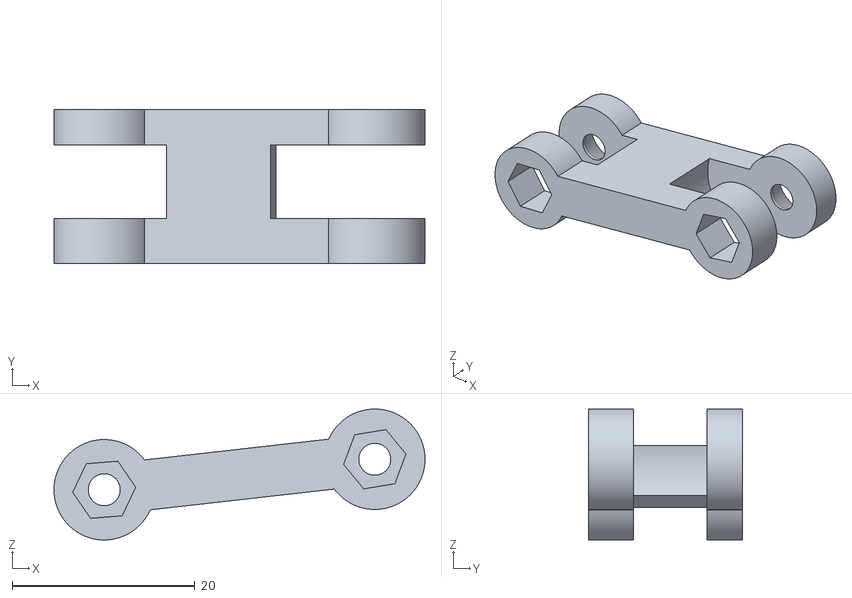
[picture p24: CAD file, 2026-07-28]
simulator/models/bar_1.stl
40.6 x 16.8 x 14.3

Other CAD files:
simulator/models/base.stl

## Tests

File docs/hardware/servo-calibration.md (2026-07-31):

# 서보 보정

앱은 5개 관절을 `-90~+90°`, Gripper를 열림 `0%`~닫힘 `100%`로 표시합니다.
패킷과 Flash에는 이를 `0~180`으로 변환해 저장합니다.

## 안전 초기값

Sector 7에 유효한 보정이 없을 때만 사용합니다. 실측 끝점이 아닙니다.

| 채널 | 관절 | -90°/열림 | 중앙 | +90°/닫힘 | 방향 |
|---:|---|---:|---:|---:|---|
| 0 | Base | 2300 | 1500 | 700 | 반전 |
| 1 | Shoulder | 2300 | 1500 | 700 | 반전 |
| 2 | Elbow | 700 | 1500 | 2300 | 기본 |
| 3 | Wrist Tilt | 2300 | 1500 | 700 | 반전 |
| 4 | Wrist Rotate | 2300 | 1500 | 700 | 반전 |
| 5 | Gripper | 1800 | 1500 | 1200 | 반전 |

단위는 µs입니다. 유효한 Flash 값이 있으면 그 값을 우선합니다.

## 실측 참고값

| 채널 | 관절 | -90° | 0° | +90° | 상태 |
|---:|---|---:|---:|---:|---|
| 0 | Base | 2500 | 1500 | 500 | 측정 완료 |
| 1 | Shoulder | 2322 | 1466 | 633 | 측정 완료 |
| 2 | Elbow | 633 | 1500 | 2388 | 측정 완료 |
| 3 | Wrist Tilt | 2500 | 1500 | 500 | 임시값 |
| 4 | Wrist Rotate | 2533 | 1500 | 500 | 측정 완료 |

Shoulder는 기존 명령 `-78/-3/+74°`, Elbow는 `-78/0/+80°`, Wrist Rotate는
`-90/0/+93°`에서 실제 `-90/0/+90°`에 도달한 측정 결과를 환산했습니다.
Wrist Tilt는 실기 끝점 확인이 필요합니다.

### Gripper 실측

| 상태 | 앱 | 패킷 | 펄스 |
|---|---:|---:|---:|
| 최대 열림 | 0% | 0 | 1840 µs |
| 중간 | 50% | 90 | 1490 µs |
| 최대 닫힘 | 100% | 180 | 1140 µs |

펄스가 커질수록 열립니다.

## 원점과 이동 자세

- 원점 패킷: `[90,90,90,90,90,0]`.
- 이동 자세: 티칭 시퀀스 9.
- 이동 자세 실행 중 Gripper는 현재값 유지.
- Gripper를 여는 것은 사용자가 `원점으로 이동`을 요청한 경우뿐입니다.

## 앱 보정

1. `원점 보정` 진입 후 전체 원점 이동 ACK를 기다립니다.
2. Base부터 Gripper까지 한 관절씩 선택합니다.
3. 일반 관절은 `-90/0/+90°`, Gripper는 열림/닫힘을 조정합니다.
4. `확인 시퀀스`로 시험합니다.
5. `원점 보정 저장`으로만 Sector 7에 기록합니다.

| 대상 | 허용 범위 |
|---|---:|
| Base~Wrist Rotate | 350~2650 µs |
| Gripper | 1000~2000 µs |

Gripper 중앙값은 두 끝점의 평균입니다. 미리보기는 한 관절만 20 ms S-curve로
움직이며 다른 관절은 원점을 유지합니다. 확인 순서는 일반 관절
`-90→+90→0°`, Gripper `열림→닫힘→열림`입니다. 값은 저장 전 앱 RAM에만
있으며 ACK와 Flash 재검증이 끝난 뒤 저장 완료로 처리합니다.

기구 걸림, 떨림 또는 과열이 나타나면 즉시 STOP 후 구동 전원을 차단합니다.

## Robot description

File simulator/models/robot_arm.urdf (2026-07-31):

<?xml version="1.0"?>
<robot name="mobile_retrieval_arm">

  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

  <link name="base_link">
    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
    <inertial>
      <origin xyz="0 0 0.020" rpy="0 0 0"/>
      <mass value="0.137140"/>
      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
    </inertial>
    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
  </link>

  <link name="base_yaw_link">
    <inertial>
      <origin xyz="0.001113 0.005163 0.016565" rpy="0 0 0"/>
      <mass value="0.114160"/>
      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
    </inertial>
    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
  </link>

  <joint name="base_yaw_joint" type="revolute">
    <parent link="base_link"/>
    <child link="base_yaw_link"/>
    <origin xyz="0 0 0.060" rpy="0 0 0"/>
    <axis xyz="0 0 1"/>
    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
    <limit lower="-1.5708" upper="1.5708" effort="1.0" velocity="1.0"/>
  </joint>

  <link name="shoulder_link">
    <inertial>
      <origin xyz="-0.000694 -0.000824 0.081211" rpy="0 0 0"/>
      <mass value="0.099100"/>
      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
    </inertial>
    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
  </link>

  <joint name="shoulder_joint" type="revolute">
    <parent link="base_yaw_link"/>
    <child link="shoulder_link"/>
    <origin xyz="0 0 0.040" rpy="0 0 0"/>
    <axis xyz="0 1 0"/>
    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
    <limit lower="-1.5708" upper="1.5708" effort="1.0" velocity="1.0"/>
  </joint>

  <link name="elbow_link">
    <inertial>
      <origin xyz="0.073480 0.001403 0.000108" rpy="0 0 0"/>
      <mass value="0.040770"/>
      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
    </inertial>
    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
  </link>

  <joint name="elbow_joint" type="revolute">
    <parent link="shoulder_link"/>
    <child link="elbow_link"/>
    <origin xyz="0 0 0.1200" rpy="0 0 0"/>
    <axis xyz="0 1 0"/>
    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
    <limit lower="-1.5708" upper="1.5708" effort="1.0" velocity="1.0"/>
  </joint>

  <link name="wrist_tilt_link">
    <inertial>
      <origin xyz="0.002825 -0.003864 0.002145" rpy="0 0 0"/>
      <mass value="0.025150"/>
      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
    </inertial>
    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
  </link>

  <joint name="wrist_tilt_joint" type="revolute">
    <parent link="elbow_link"/>
    <child link="wrist_tilt_link"/>
    <origin xyz="0.120 0 0" rpy="0 0 0"/>
    <axis xyz="0 1 0"/>
    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
    <limit lower="-1.5708" upper="1.5708" effort="1.0" velocity="1.0"/>
  </joint>

  <link name="wrist_rotate_link">
    <inertial>
      <origin xyz="0.017649 0.007816 -0.002994" rpy="0 0 0"/>
      <mass value="0.021440"/>
      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
    </inertial>
    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
  </link>

  <joint name="wrist_rotate_joint" type="revolute">
    <parent link="wrist_tilt_link"/>
    <child link="wrist_rotate_link"/>
    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
    <origin xyz="0 0 0" rpy="-1.5708 0 0"/>
    <axis xyz="1 0 0"/>
    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
    <limit lower="-1.5708" upper="1.5708" effort="1.0" velocity="1.0"/>
  </joint>

  <link name="gripper_finger_1_link">
    <inertial>
      <origin xyz="0.029076 -0.000567 -0.000355" rpy="0 0 0"/>
      <mass value="0.011850"/>
      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
    </inertial>
    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
  </link>

  <joint name="gripper_finger_1_joint" type="revolute">
    <parent link="wrist_rotate_link"/>
    <child link="gripper_finger_1_link"/>
    <origin xyz="0.04617 -0.00150 -0.01204" rpy="0 0 0"/>
    <axis xyz="0 1 0"/>
    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
    <limit lower="-0.18" upper="0.25" effort="0.08" velocity="3.0"/>
    <dynamics damping="0.004" friction="0.002"/>
  </joint>

  <link name="gripper_finger_2_link">
    <inertial>
      <origin xyz="0.030123 -0.000773 0.000841" rpy="0 0 0"/>
      <mass value="0.011610"/>
      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
    </inertial>
    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
  </link>

  <joint name="gripper_finger_2_joint" type="revolute">
    <parent link="wrist_rotate_link"/>
    <child link="gripper_finger_2_link"/>
    <origin xyz="0.04595 -0.00119 0.01184" rpy="0 0 0"/>
    <axis xyz="0 1 0"/>
    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
    <limit lower="-0.25" upper="0.18" effort="0.08" velocity="3.0"/>
    <dynamics damping="0.004" friction="0.002"/>
  </joint>

  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
  <link name="tcp_link">
    <inertial>
      <origin xyz="0 0 0" rpy="0 0 0"/>
      <mass value="0.000001"/>
      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
    </inertial>
  </link>
  <joint name="tcp_fixed_joint" type="fixed">
    <parent link="wrist_rotate_link"/>
    <child link="tcp_link"/>
    <origin xyz="0.125 0 0" rpy="0 0 0"/>
  </joint>

</robot>

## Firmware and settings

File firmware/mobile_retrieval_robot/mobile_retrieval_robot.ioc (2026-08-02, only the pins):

Mcu.UserName=STM32F411RETx
PA10.Signal=USART1_RX
PA13.GPIO_Label=TMS
PA13.Signal=SYS_JTMS-SWDIO
PA14.GPIO_Label=TCK
PA14.Signal=SYS_JTCK-SWCLK
PA5.GPIO_Label=LD2 [Green Led]
PA5.Signal=GPIO_Output
PA8.GPIO_Label=I2C3_SCL_IMU
PA8.Signal=I2C3_SCL
PA0-WKUP.GPIO_Label=MOTOR_L_ENA_PWM
PA0-WKUP.Signal=S_TIM2_CH1_ETR
PA1.GPIO_Label=MOTOR_R_ENB_PWM
PA1.Signal=S_TIM2_CH2
PA9.GPIO_Label=BT_TX_TO_HC05_RX
PA9.Signal=USART1_TX
PA10.GPIO_Label=BT_RX_FROM_HC05_TX
PB3.GPIO_Label=SWO
PB3.Signal=SYS_JTDO-SWO
PB8.GPIO_Label=I2C1_SCL_PCA9685
PB8.Signal=I2C1_SCL
PB9.GPIO_Label=I2C1_SDA_PCA9685
PB9.Signal=I2C1_SDA
PC14-OSC32_IN.Signal=RCC_OSC32_IN
PC15-OSC32_OUT.Signal=RCC_OSC32_OUT
PC0.GPIO_Label=MOTOR_L_IN1
PC0.Signal=GPIO_Output
PC1.GPIO_Label=MOTOR_L_IN2
PC1.Signal=GPIO_Output
PC2.GPIO_Label=MOTOR_R_IN3
PC2.Signal=GPIO_Output
PC3.GPIO_Label=MOTOR_R_IN4
PC3.Signal=GPIO_Output
PC9.GPIO_Label=I2C3_SDA_IMU
PC9.Signal=I2C3_SDA

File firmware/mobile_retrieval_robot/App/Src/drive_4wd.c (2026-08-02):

#include "drive_4wd.h"

#include <math.h>
#include <stddef.h>
#include <string.h>

#include "main.h"

/*
 * L298N 좌우 모터 그룹과 MPU6050 상대 Yaw PID를 함께 관리한다.
 * 모든 실제 PWM 기록은 High 우선순위 DriveTask에서 수행하며, E-STOP과
 * 통신·Flash·로봇팔·IMU 인터록이 PID보다 항상 먼저 적용된다.
 */

#define DRIVE_PWM_MAX              (999U)
#define APP_PWM_MAX                (255U)
#define MIN_PWM_THRESHOLD          (15U)
#define DRIVE_TIMEOUT_MS           (500U)
#define PID_KP_MAX_MILLI           (2550L)
#define PID_GAIN_MAX_MILLI         (100000L)
#define PID_KP_STEP_MILLI          (10L)
#define PID_INTEGRAL_LIMIT         (50.0f)
#define PID_OUTPUT_LIMIT           (80.0f)
#define PID_SAMPLE_MAX_MS          (200U)
#define PID_CORRECTION_SIGN        (-1.0f)

static TIM_HandleTypeDef *drive_timer;
static uint32_t last_command_tick;
static volatile uint8_t command_received;
static volatile uint8_t estop_latched;
static volatile uint8_t storage_inhibit;
static volatile uint8_t arm_motion_inhibit;
static volatile uint8_t imu_calibration_inhibit;
static volatile uint8_t pid_transition_inhibit;
static volatile uint8_t fresh_drive_command_required;
static volatile uint8_t pid_enabled;
static volatile uint8_t imu_available;
static volatile uint8_t pid_gains_valid;
static volatile uint32_t drive_inhibit_release_tick;

static BluetoothDriveCommand active_command;
static uint8_t pid_straight_active;
static uint8_t pid_target_pending;
static uint8_t applied_left_direction;
static uint8_t applied_right_direction;
static uint8_t applied_left_pwm;
static uint8_t applied_right_pwm;
static float pid_kp;
static float pid_ki;
static float pid_kd;
static float pid_target_yaw;
static float pid_integral;
static float pid_previous_error;
static uint32_t pid_previous_sample_tick;
static DrivePidStatus pid_status;

/* 한쪽 모터의 두 방향 핀을 전진·후진·중립 상태로 설정한다. */
static void SetMotorDirection(GPIO_TypeDef *in1_port,
                              uint16_t in1_pin,
                              GPIO_TypeDef *in2_port,
                              uint16_t in2_pin,
                              uint8_t direction,
                              uint8_t pwm)
{
  GPIO_PinState in1 = GPIO_PIN_RESET;
  GPIO_PinState in2 = GPIO_PIN_RESET;

  if (pwm != 0U)
  {
    if (direction == 0U)
    {
      in1 = GPIO_PIN_SET;
    }
    else
    {
      in2 = GPIO_PIN_SET;
    }
  }

  HAL_GPIO_WritePin(in1_port, in1_pin, in1);
  HAL_GPIO_WritePin(in2_port, in2_pin, in2);
}

/* 앱의 0~255 속도를 TIM2의 0~999 Compare 값으로 바꾼다. */
static uint32_t ScalePwm(uint8_t pwm)
{
  if (pwm < MIN_PWM_THRESHOLD)
  {
    return 0U;
  }
  return ((uint32_t)pwm * DRIVE_PWM_MAX) / APP_PWM_MAX;
}

static uint8_t ClampPwm(int32_t pwm)
{
  if (pwm <= 0)
  {
    return 0U;
  }
  if (pwm >= (int32_t)APP_PWM_MAX)
  {
    return APP_PWM_MAX;
  }
  return (uint8_t)pwm;
}

/* -180~+180도 범위에서 가장 짧은 방향 오차를 만든다. */
static float WrapYawError(float error)
{
  while (error > 180.0f)
  {
    error -= 360.0f;
  }
  while (error < -180.0f)
  {
    error += 360.0f;
  }
  return error;
}

static uint8_t IsInhibited(void)
{
  return (uint8_t)((estop_latched != 0U) ||
                   (storage_inhibit != 0U) ||
                   (arm_motion_inhibit != 0U) ||
                   (imu_calibration_inhibit != 0U) ||
                   (pid_transition_inhibit != 0U));
}

/* 목표와 누적항을 버려 다음 직진 구간에서 새 Yaw를 기준으로 잡는다. */
static void ResetPidMotion(void)
{
  pid_straight_active = 0U;
  pid_target_pending = 0U;
  pid_target_yaw = 0.0f;
  pid_integral = 0.0f;
  pid_previous_error = 0.0f;
  pid_previous_sample_tick = 0U;
  pid_status.pid_running = 0U;
  pid_status.target_updated = 0U;
  pid_status.target_yaw_deg = 0.0f;
  pid_status.error_deg = 0.0f;
  pid_status.output = 0.0f;
}

/* 방향 GPIO보다 PWM을 먼저 내린 뒤 좌우 출력을 함께 갱신한다. */
static void ApplyMotorOutput(uint8_t left_direction,
                             uint8_t left_pwm,
                             uint8_t right_direction,
                             uint8_t right_pwm)
{
  uint32_t left_compare;
  uint32_t right_compare;

  if (drive_timer == NULL)
  {
    return;
  }

  left_compare = ScalePwm(left_pwm);
  right_compare = ScalePwm(right_pwm);
  __HAL_TIM_SET_COMPARE(drive_timer, TIM_CHANNEL_1, 0U);
  __HAL_TIM_SET_COMPARE(drive_timer, TIM_CHANNEL_2, 0U);
  SetMotorDirection(MOTOR_L_IN1_GPIO_Port,
                    MOTOR_L_IN1_Pin,
                    MOTOR_L_IN2_GPIO_Port,
                    MOTOR_L_IN2_Pin,
                    left_direction,
                    (uint8_t)(left_compare != 0U));
  SetMotorDirection(MOTOR_R_IN3_GPIO_Port,
                    MOTOR_R_IN3_Pin,
                    MOTOR_R_IN4_GPIO_Port,
                    MOTOR_R_IN4_Pin,
                    right_direction,
                    (uint8_t)(right_compare != 0U));
  __HAL_TIM_SET_COMPARE(drive_timer, TIM_CHANNEL_1, left_compare);
  __HAL_TIM_SET_COMPARE(drive_timer, TIM_CHANNEL_2, right_compare);

  applied_left_direction = left_direction;
  applied_right_direction = right_direction;
  applied_left_pwm = (left_compare == 0U) ? 0U : left_pwm;
  applied_right_pwm = (right_compare == 0U) ? 0U : right_pwm;
  pid_status.left_pwm = applied_left_pwm;
  pid_status.right_pwm = applied_right_pwm;
}

HAL_StatusTypeDef Drive4WD_Init(TIM_HandleTypeDef *timer)
{
  if (timer == NULL)
  {
    return HAL_ERROR;
  }

  drive_timer = timer;
  if ((HAL_TIM_PWM_Start(drive_timer, TIM_CHANNEL_1) != HAL_OK) ||
      (HAL_TIM_PWM_Start(drive_timer, TIM_CHANNEL_2) != HAL_OK))
  {
    return HAL_ERROR;
  }

  memset(&active_command, 0, sizeof(active_command));
  memset(&pid_status, 0, sizeof(pid_status));
  estop_latched = 1U;
  storage_inhibit = 0U;
  arm_motion_inhibit = 0U;
  imu_calibration_inhibit = 0U;
  pid_transition_inhibit = 0U;
  pid_enabled = 0U;
  imu_available = 0U;
  fresh_drive_command_required = 0U;
  drive_inhibit_release_tick = 0U;
  command_received = 0U;
  ResetPidMotion();
  Drive4WD_Stop();
  return HAL_OK;
}
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

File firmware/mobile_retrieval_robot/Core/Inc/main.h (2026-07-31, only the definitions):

#define LD2_Pin GPIO_PIN_5
#define LD2_GPIO_Port GPIOA
#define MOTOR_L_IN1_Pin GPIO_PIN_0
#define MOTOR_L_IN1_GPIO_Port GPIOC
#define MOTOR_L_IN2_Pin GPIO_PIN_1
#define MOTOR_L_IN2_GPIO_Port GPIOC
#define MOTOR_R_IN3_Pin GPIO_PIN_2
#define MOTOR_R_IN3_GPIO_Port GPIOC
#define MOTOR_R_IN4_Pin GPIO_PIN_3
#define MOTOR_R_IN4_GPIO_Port GPIOC
#define TMS_Pin GPIO_PIN_13
#define TMS_GPIO_Port GPIOA
#define TCK_Pin GPIO_PIN_14
#define TCK_GPIO_Port GPIOA
#define SWO_Pin GPIO_PIN_3
#define SWO_GPIO_Port GPIOB

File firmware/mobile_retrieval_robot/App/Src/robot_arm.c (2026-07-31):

#include "robot_arm.h"

#include <string.h>

#include "servo_driver.h"

/*
 * 6개 관절의 명령 각도, 목표 각도와 티칭 재생 상태를 관리한다.
 * 위치 센서가 없으므로 current_angles는 실측값이 아니라 마지막 PWM 명령값이다.
 */

#define ARM_CONTROL_INTERVAL_MS (20U)
#define ARM_REFERENCE_STEP_INTERVAL_MS (16U)
#define ARM_RAMP_STEPS (12U)
#define ARM_TRAJECTORY_SAMPLE_COUNT (32U)
#define ARM_TRAJECTORY_SEARCH_COUNT (32U)
#define ARM_HOLD_TIME_MS (400U)
#define ARM_CALIBRATION_MIN_US (350U)
#define ARM_CALIBRATION_MAX_US (2650U)
#define ARM_GRIPPER_CALIBRATION_MIN_US (1000U)
#define ARM_GRIPPER_CALIBRATION_MAX_US (2000U)
#define ARM_PREVIEW_TIMEOUT_MS (2000U)
#define ARM_SPEED_MIN_PERCENT (50U)
#define ARM_SPEED_MAX_PERCENT (100U)

typedef enum { ARM_IDLE = 0, ARM_MOVING, ARM_HOLDING } ArmState;

typedef struct {
  ServoCalibration calibration;
  uint8_t min_angle;
  uint8_t max_angle;
  uint8_t reversed;
  uint8_t calibrated;
} JointConfig;

/*
 * Flash 보정값이 없을 때는 좁힌 안전 초기 범위를 사용한다.
 * 조립 후 앱의 관절별 보정 화면에서 실제 세 지점을 다시 저장한다.
 */
static JointConfig joint_config[ROBOT_ARM_JOINT_COUNT] = {
    {{700U, 1500U, 2300U}, 0U, 180U, 1U, 1U}, /* Base: 방향 반전 */
    {{700U, 1500U, 2300U}, 0U, 180U, 1U, 1U}, /* Shoulder: 방향 반전 */
    {{700U, 1500U, 2300U}, 0U, 180U, 0U, 1U}, /* Elbow */
    {{700U, 1500U, 2300U}, 0U, 180U, 1U, 1U}, /* Wrist Tilt: 방향 반전 */
    {{700U, 1500U, 2300U}, 0U, 180U, 1U, 1U}, /* Wrist Rotate: 방향 반전 */
    {{1200U, 1500U, 1800U}, 0U, 180U, 1U, 1U} /* Gripper: 방향 반전 */
};

/* 모든 일반 관절은 표시 0도, Gripper는 최대 열림 0%를 홈으로 사용한다. */
static const uint8_t origin_angles[ROBOT_ARM_JOINT_COUNT] = {
    90U, 90U, 90U, 90U, 90U, 0U};

static uint8_t current_angles[ROBOT_ARM_JOINT_COUNT];
static uint8_t target_angles[ROBOT_ARM_JOINT_COUNT];
static const TeachingSequence *active_sequence;
static uint8_t waypoint_index;
static uint8_t arm_enabled;
static uint8_t arm_initialized;
static uint8_t pose_reached_pending;
static uint8_t speed_warning_pending;
static uint8_t preserve_sequence_gripper;
static uint8_t speed_percent = ARM_SPEED_MAX_PERCENT;
static uint8_t preview_active;
static uint8_t preview_moving;
static uint8_t preview_joint;
static uint8_t preview_position_valid;
static uint8_t preview_position_joint;
static uint8_t preview_request_id;
static uint8_t preview_result_pending;
static RobotArmResult preview_result;
static uint16_t preview_target_pulse_us;
static float preview_position_us;
static float preview_velocity_us_s;
static float preview_acceleration_us_s2;
static float preview_coefficients[6];
static float preview_duration_s;
static float preview_elapsed_s;
static uint32_t preview_command_tick;
static uint32_t preview_motion_tick;
static uint32_t state_tick;
static uint32_t motion_tick;
static float motion_positions[ROBOT_ARM_JOINT_COUNT];
static float motion_velocities[ROBOT_ARM_JOINT_COUNT];
static float motion_accelerations[ROBOT_ARM_JOINT_COUNT];
static float trajectory_coefficients[ROBOT_ARM_JOINT_COUNT][6];
static float trajectory_duration_s;
static float trajectory_elapsed_s;
static uint16_t last_pulse_widths_us[ROBOT_ARM_JOINT_COUNT];
static ArmState arm_state;

static float AbsFloat(float value) {
  return (value < 0.0F) ? -value : value;
}

/* 조립 방향이 반전된 관절의 논리 위치를 실제 출력 방향으로 바꾼다. */
static float GetOutputPosition(uint8_t joint, float position) {
  if (joint_config[joint].reversed != 0U) {
    return (float)joint_config[joint].max_angle -
           (position - (float)joint_config[joint].min_angle);
  }

  return position;
}

/*
 * 3점 보정값 사이를 소수점 위치로 보간한다.
 * 1도 단위로 끊지 않아 낮은 속도에서도 PCA9685 펄스가 고르게 변한다.
 */
static uint16_t GetPulseWidthForPosition(uint8_t joint, float position) {
  const ServoCalibration *calibration = &joint_config[joint].calibration;
  float output_position = GetOutputPosition(joint, position);
  float pulse_width;

  if (output_position <= 90.0F) {
    pulse_width =
        (float)calibration->min_pulse_us +
        (((float)calibration->center_pulse_us -
          (float)calibration->min_pulse_us) *
         (output_position / 90.0F));
  } else {
    pulse_width =
        (float)calibration->center_pulse_us +
        (((float)calibration->max_pulse_us -
          (float)calibration->center_pulse_us) *
         ((output_position - 90.0F) / 90.0F));
  }

  return (uint16_t)(pulse_width + 0.5F);
}

/* 이동을 멈출 때 속도와 가속도만 0으로 만든다. */
static void StopMotion(void) {
  uint8_t joint;

  for (joint = 0U; joint < ROBOT_ARM_JOINT_COUNT; joint++) {
    motion_velocities[joint] = 0.0F;
    motion_accelerations[joint] = 0.0F;
  }
}

/* 6개 관절에 유효한 3점 보정값이 모두 등록됐는지 확인한다. */
static uint8_t AreAllJointsCalibrated(void) {
  uint8_t joint;

  for (joint = 0U; joint < ROBOT_ARM_JOINT_COUNT; joint++) {
    if (joint_config[joint].calibrated == 0U) {
      return 0U;
    }
  }

  return 1U;
}

static RobotArmResult
ValidatePose(const uint8_t angles[ROBOT_ARM_JOINT_COUNT]) {
  uint8_t joint;

  if (angles == NULL) {
    return ROBOT_ARM_INVALID;
  }

  if (AreAllJointsCalibrated() == 0U) {
    return ROBOT_ARM_NOT_CALIBRATED;
  }

  for (joint = 0U; joint < ROBOT_ARM_JOINT_COUNT; joint++) {
    if ((angles[joint] < joint_config[joint].min_angle) ||
        (angles[joint] > joint_config[joint].max_angle)) {
      return ROBOT_ARM_INVALID;
    }
  }

  return ROBOT_ARM_OK;
}

/* 한 관절의 소수점 위치를 펄스폭으로 바꿔 PCA9685 채널에 출력한다. */
static HAL_StatusTypeDef SetJointPosition(uint8_t joint, float position) {
  HAL_StatusTypeDef status;
  uint16_t pulse_width_us;
  uint8_t rounded_angle;

  if ((joint >= ROBOT_ARM_JOINT_COUNT) ||
      (joint_config[joint].calibrated == 0U) ||
      (position < (float)joint_config[joint].min_angle) ||
      (position > (float)joint_config[joint].max_angle)) {
    return HAL_ERROR;
  }

  pulse_width_us = GetPulseWidthForPosition(joint, position);
  if (pulse_width_us != last_pulse_widths_us[joint]) {
    status = ServoDriver_SetPulseUs(joint, pulse_width_us);
    if (status != HAL_OK) {
      return status;
    }
    last_pulse_widths_us[joint] = pulse_width_us;
  }

  motion_positions[joint] = position;
  rounded_angle = (uint8_t)(position + 0.5F);
  current_angles[joint] = rounded_angle;
  return HAL_OK;
}
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

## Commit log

2026-07-24 docs: add STM32 pin map
2026-07-25 refactor: add STM32 firmware root folder
2026-07-25 refactor: move STM32 ignore rules into firmware
2026-07-25 refactor: move pin map into docs
2026-07-25 docs: replace wheel encoders with ultrasonic arm safety interlock
2026-07-25 docs: add ultrasonic sensor wiring and safety notes
2026-07-25 docs: set arm deployment distance to 20 cm
2026-07-25 docs: set arm deployment cutoff to 20 cm
2026-07-25 docs: add project bill of materials
2026-07-25 docs: link bill of materials and clarify phase-one scope
2026-07-26 firmware: add STM32F411 project scaffold
2026-07-28 feat: implement robot control stack and companion tools
    [bar_1.stl, bar_2.stl, base.stl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]
2026-07-31 feat: complete robot control workflow
    - unify app and firmware on the 16-byte protocol
    - add teaching, servo calibration, and yaw PID
    - document hardware, safety, and validation
    [robot_arm.urdf]
2026-07-31 fix(firmware): match vehicle wiring
    [drive_4wd.c, main.h, mobile_retrieval_robot.ioc]
2026-08-02 fix(control): stabilize IMU and PID flow
    [bluetooth.c, bluetooth.h, drive_4wd.c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]
2026-08-03 feat(app): sync poses and tune straight input
    Lock saved-sequence playback while loading its final pose so manual controls cannot diverge from completed arm actions.
2026-08-03 docs: explain servo and yaw PID control

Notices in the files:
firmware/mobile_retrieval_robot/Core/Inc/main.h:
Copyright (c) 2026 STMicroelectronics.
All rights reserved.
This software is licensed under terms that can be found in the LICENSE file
